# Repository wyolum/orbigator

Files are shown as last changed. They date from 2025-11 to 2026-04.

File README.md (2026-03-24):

# 🌍 Orbigator: The Analog Orbit Propagator






> "What hardware hacker doesn’t have a soft spot for transparent cases? ... [wyojustin] has done a fantastic job of documenting the hardware and software aspects of the build." — **[Hackaday](https://hackaday.com/2026/03/08/the-orbigator-satellite-tracking-with-style/)** ([Full Feature Archive](docs/HACKADAY_FEATURE.md))

**The Orbigator** is an open-source, physical satellite tracker that turns complex orbital mechanics into a desk-side companion. Powered by the **Raspberry Pi Pico 2** and precision **DYNAMIXEL servos**, it physically points to the ISS (or any satellite) in real-time with zero drift.

---

## 🚀 Why the Orbigator?

Inspired by [Will’s Builds ISS tracker](https://hackaday.com/2025/07/08/touch-lamp-tracks-iss-with-style/), the Orbigator introduces several key technical innovations to the DIY tracker space:

### 🔄 Continuous, Uninterrupted Motion
Unlike traditional trackers that use static globes (requiring wire unwinding every orbit), the Orbigator features a **rotating globe**. This allows for smooth, continuous tracking across multiple revolutions without ever needing to reset or "unwind."

### 🎯 LVLH Attitude Control
The orbital mechanics are implemented directly in the hardware geometry (inclination angle). This ensures the satellite pointer maintains a true **LVLH (Local Vertical, Local Horizontal)** attitude throughout the entire pass—exactly how real satellites orient themselves.

### 🧩 Zero-Drift absolute Positioning
Leveraging the 32-bit absolute resolvers in DYNAMIXEL XL330-M288-T motors, the system recovers its orientation instantly after power cycles. No homing, no limits, and no drift—just persistent, mathematical accuracy.

---

## 🛠️ Technical Deep Dive

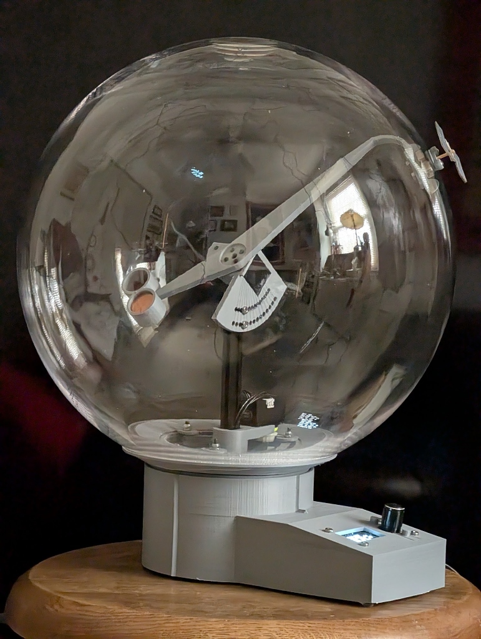
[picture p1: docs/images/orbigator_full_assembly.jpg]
Full Assembly

*Complete Mechanical Assembly: Precision motion and integrated control.*

### Lightweight, High-Performance Propagator
The heart of the Orbigator is a custom, **lightweight SGP4 implementation** running natively on the Pico 2's RISC-V cores. Eschewing heavy ports, it was rolled specifically to provide mathematical accuracy within the visual tolerances of the physical hardware, handling real-time TLE propagation and J2 perturbation effects entirely in MicroPython.

### Split-Screen Radar UI
A custom **SH1106 OLED driver** provides a powerful command center:
*   **Live Radar Plot**: A dynamic "Sky Plot" of the current satellite pass.
*   **Localized World Map**: High-speed bitmask rendering provides a 90° ground track view centered on your observer location.

### Smart Persistence
The system monitors its own state and saves to Flash/SRAM only during ideal intervals (e.g., at equator crossings) to maximize flash lifespan while ensuring a perfect "instant-on" recovery.

---

## 📦 Repository Structure

| Path | Description |
|---|---|
| [**micropython/**](micropython/) | Firmware: SGP4 propagator, UI stacks, and motor drivers. |
| [**fabricate/**](fabricate/) | Mechanical design: OpenSCAD files for 3D printing and assembly. |
| [**kicad/**](kicad/) | Electronics: PCB designs and schematics. |
| [**web/**](micropython/web/) | Dashboard: Real-time control and configuration via web interface. |

---

## ⚡ Quick Start

1.  **3D Print**: High-quality production STLs are located in [**fabricate/stls/Production/**](fabricate/stls/Production/).
2.  **Assemble**: Follow our step-by-step [**Assembly Instructions**](docs/ASSEMBLY.md).
3.  **Flash MicroPython**: Install the Pico 2 firmware.
4.  **Upload Code**: Use Thonny or `mpremote` to copy the `micropython/` files to the board.
5.  **Track!**: Power up and select your satellite from the "SGP4" menu.

---

## 🧾 Bill of Materials (BOM)

### Electronics
*   **Controller**: [Raspberry Pi Pico 2W](https://www.adafruit.com/product/6087)
*   **Motors**: 2x [DYNAMIXEL XL330-M288-T](https://robotis.us/dynamixel-xl330-m288-t/)
*   **Display/UI**: [I2C OLED Display with EC11 Rotary Encoder](https://www.crcibernetica.com/i2c-oled-display-with-ec11-rotary-encoder/) (includes 2x buttons)
*   **RTC**: [DS3232 Precision RTC](https://www.dfrobot.com/product-2304.html)
*   **Logic**: 1x [SN74HC126N Quad Tri-State Buffer](https://www.digikey.com/en/products/detail/texas-instruments/SN74HC126N/376889) (for half-duplex UART)
*   **Passives**: 1x 10kΩ resistor, 2x 4.7kΩ resistors
*   **Power**: 5V 4-5A External Power Supply with [5.5mm DC Barrel Jack](https://www.amazon.com/dp/B0D9B7WR23)

### Hardware & Mechanical
*   **Globe**: [12" Transparent Desktop Globe](https://www.amazon.com/dp/B0086OHL9A)
*   **Bearings**: 3x [13mm OD Carbon Steel Ball Bearings](https://www.amazon.com/dp/B07SV6QSR3) (e.g., 624ZZ) and [High-Performance Skate Bearings](https://www.amazon.com/dp/B09MPMW1XQ)
*   **Fasteners**: Self-tapping screws (included with motors), [M3 Male Stud Mounting Magnets](https://www.kjmagnetics.com/mm-c-12-neodymium-male-stud-mounting-magnet?pl=1.2&pf=), and [Tension Springs](https://www.amazon.com/dp/B076LZ8L1M)
*   **Hardware**: 10-20 US pennies (used as counterweight)
*   **3D Parts**: Printed from the `Production/` folder (PLA or PETG)

---

## 📐 3D Printing (Production Parts)

The following parts are required for the full assembly and can be found in `fabricate/stls/Production/`. **The leading number in the filename indicates the required print quantity.**

*   `1_drive_gear.stl` - Main EQX drive
*   `1_flex_aov_arm.stl` - Satellite pointer arm
*   `1_globe_interface.stl` - Secure mount for the globe
*   `1_inclination_aov_mount.stl` - Hardware-implemented inclination bracket
*   `1_sled_3.stl` - Electronic housing and base
*   `1_full_assembly.stl` - Reference model (not for printing)
*   `3_swingarm.stl` - Differential assembly components
*   `3_shim.stl` - Insert for the skate bearings (see `misc.scad` for 13mm dims)
*   `3_washer.stl` - Vertical stop for the ring gear

---

## 📸 Media: As Seen on [WyoLum Blog](https://wyolum.com/orbigator-real-time-satellite-tracker-with-overhead-alert-radar/)

| [**Earthrise Shot**](docs/images/orbigator_lunar_display.jpg) | [**World Map Tracking**](docs/images/orbigator_worldmap_tracking.png) |
|:---:|:---:|
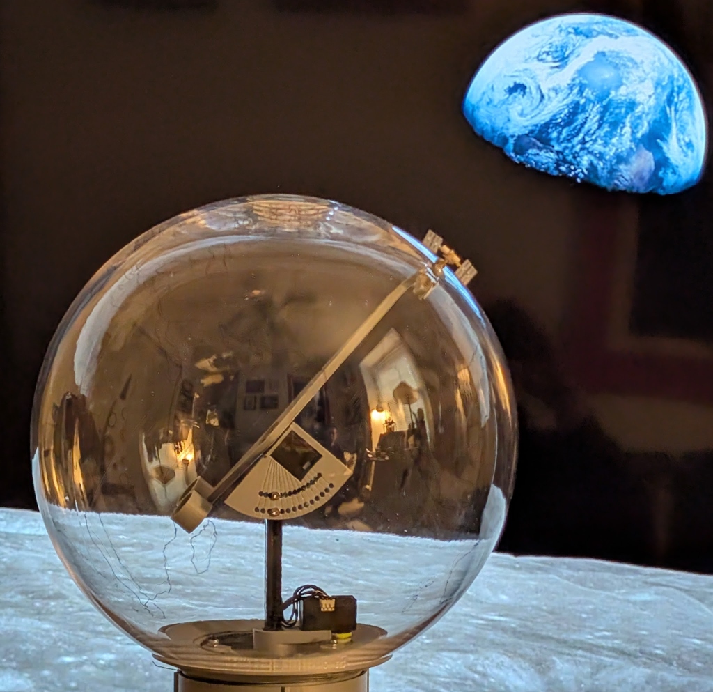
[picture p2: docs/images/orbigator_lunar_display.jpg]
Earthrise
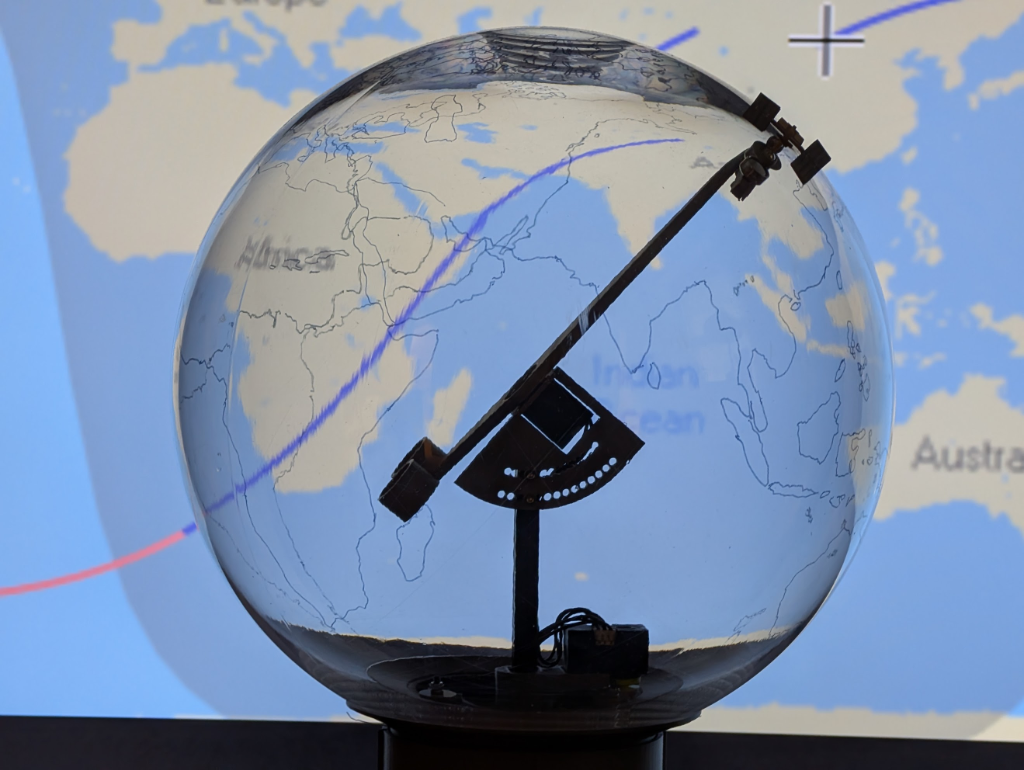
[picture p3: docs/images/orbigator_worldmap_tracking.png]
World Map
|  |  |
| *ISS Tracking with Lunar Projection.* | *Real-time World Map Context.* |

### System Details
| UI & Setup | Electronics | Mechanical Assembly | Technical Render |
|:---:|:---:|:---:|:---:|
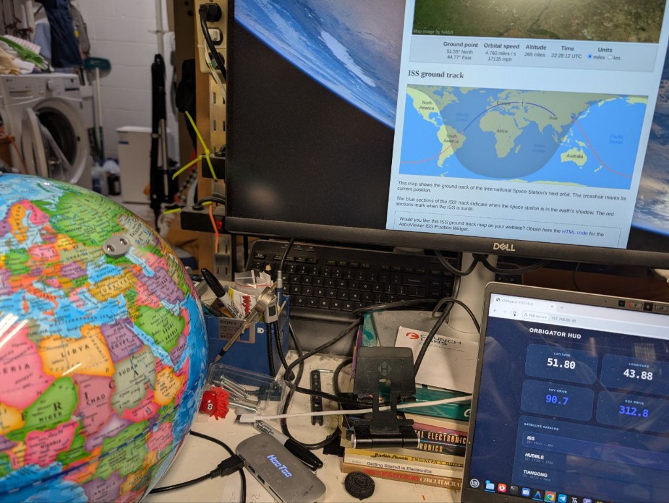
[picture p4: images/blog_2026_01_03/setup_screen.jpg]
Setup
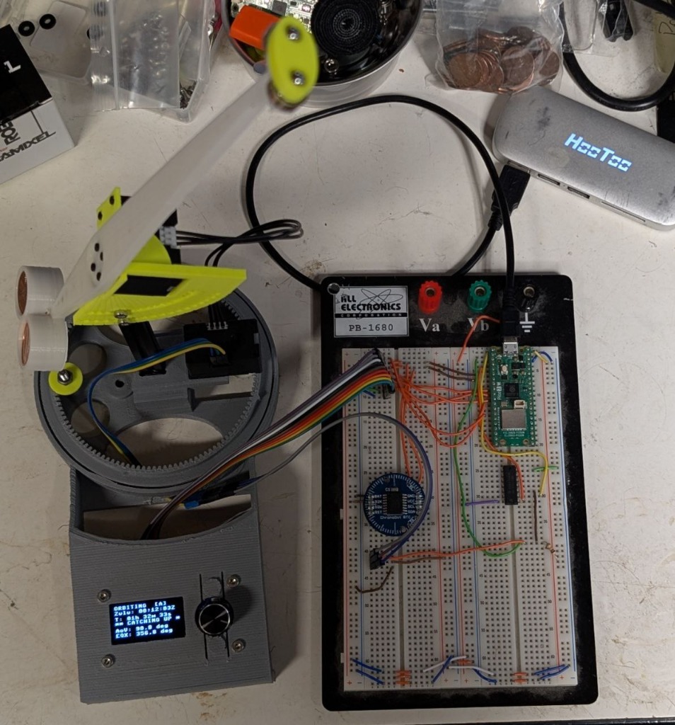
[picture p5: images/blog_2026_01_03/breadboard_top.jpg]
Circuit
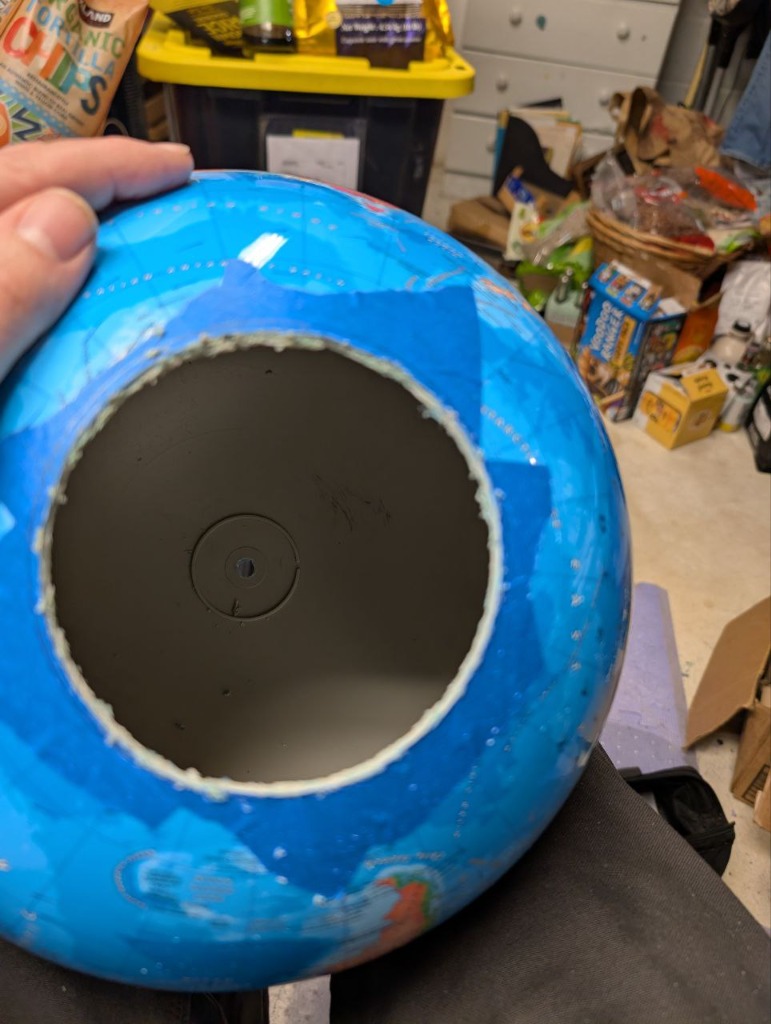
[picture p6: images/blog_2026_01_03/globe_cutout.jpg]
Globe
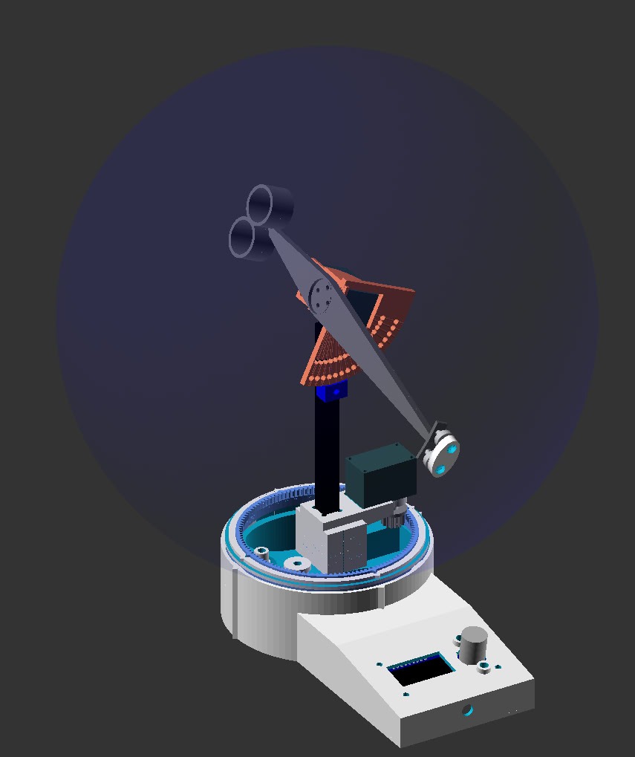
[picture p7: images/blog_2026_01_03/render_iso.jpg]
Technical View
|  |  |  |  |
| *Real-time status* | *Pico 2 & Buffers* | *Internal Hardware* | *Mathematical precision* |

> "A beautiful mix of technical precision and mechanical elegance."

---

## ⚖️ License

Distributed under the MIT License.

---

**Developed with ❤️ by wyojustin**
[GitHub](https://github.com/wyolum/orbigator)

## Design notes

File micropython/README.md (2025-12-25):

# Orbigator MicroPython Firmware

This directory contains the firmware for the Orbigator orbital mechanics simulator project running on a Raspberry Pi Pico 2.

## Main Firmware Architecture

The firmware uses a mode-based architecture for clean UI state management and precise orbital tracking.

### Core Modules
- **`orbigator.py`**: The main entry point. Initializes hardware (motors, display, RTC, encoder) and runs the main event loop.
- **`modes.py`**: Defines the UI states (Orbit, Menu, Setting Editors).
- **`orb_utils.py`**: Core logic for orbital mechanics (Kepler's Laws, J2 Precession), persistence, and motor position reconstruction.
- **`orb_globals.py`**: Central hub for shared state to break circular dependencies.
- **`dynamixel_motor.py`**: Abstraction layer for DYNAMIXEL XL330-M288-T motors.

## Key Features

### 1. Robust State Persistence
The system saves its orbital state (altitude, inclination, absolute motor positions, and timestamp) to `orbigator_config.json`.
- **Flash Protection**: To prevent flash wear, saves only occur when a motor completes a full 360° revolution.
- **Absolute Reconstruction**: On boot, the system reads the raw 0-4095 position from the DYNAMIXEL motors and reconstructs their multi-turn absolute position based on the last saved state.

### 2. Intelligent Catch-up
On startup, the system:
1. Calculates the time elapsed since the last save using the DS3231 RTC.
2. Determines the new target orbital positions.
3. Performs a **shortest-path catch-up move** (max 180°) at a safe speed limit to snap the system into the current real-time state.

### 3. Hardware Safety
- **Speed Caps**: All motors are strictly capped at a **Safety Maximum speed of 10** (Profile Velocity) to prevent mechanical damage or magnets flying off.
- **Soft Limits**: The UI ensures parameters stay within realistic bounds (e.g., altitude 200km - 2000km).

## User Interface (UI)
- **Time Display**: Zulu/UTC format (e.g., `13:24:11Z`).
- **Rotary Encoder**: 
  - **Clockwise**: Navigate Down / Increase Value / Nudge Forward.
  - **Counter-Clockwise**: Navigate Up / Decrease Value / Nudge Backward.
- **Button**: Use the encoder press to toggle targets (AoV vs EQX) or confirm selections.
- **Safety**: The 'Confirm' button is disabled during Orbiting mode to prevent accidental interruptions.

## Hardware Configuration
- **DYNAMIXEL EQX (ID 1)**: Rotates the orbital plane (10.909:1 gear ratio).
- **DYNAMIXEL AoV (ID 2)**: Direct-drive for satellite position.
- **Buffer**: 74HC126 for half-duplex UART communication.
- **RTC**: DS3231 for accurate timekeeping.

## Uploading Firmware
Use `mpremote` or Thonny to upload the entire contents of this directory to your Pico 2.
```bash
mpremote fs cp orb_globals.py orb_utils.py modes.py dynamixel_motor.py orbigator.py :
```

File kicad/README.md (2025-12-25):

# Orbigator KiCad Project

This directory contains the KiCad PCB design files for the Orbigator orbital mechanics simulator.

## Project Structure

```
kicad/
├── orbigator.kicad_pro      # KiCad 8.x project file
├── orbigator.kicad_sch      # Main schematic file
├── orbigator.kicad_pcb      # PCB layout file
├── sym-lib-table            # Symbol library table
├── fp-lib-table             # Footprint library table
├── orbigator.pretty/        # Custom footprints
├── bom/                     # Bill of Materials exports
├── gerber/                  # Gerber files for manufacturing
├── pdf/                     # PDF exports of schematics
├── renders/                 # PCB renders
├── 3D_models/               # Custom 3D models
└── orbigator-backups/       # Automatic backups
```

## Quick Start

1. Open `orbigator.kicad_pro` in KiCad 8.x
2. Review the schematic in the Schematic Editor
3. Use the reference documentation in the parent directory:
   - `ORBIGATOR_CIRCUIT_DIAGRAM.txt` - ASCII circuit diagram
   - `ORBIGATOR_PIN_ASSIGNMENTS.txt` - Pin assignments
   - `NOTE_FOR_ANOOL_I2C_PULLUPS.txt` - Critical design notes
   - `BOM.md` - Detailed component specifications

## Key Design Requirements

### Critical Components
- **I2C Pull-ups**: 4.7kΩ resistors on SDA and SCL (REQUIRED for multi-device bus)
- **RTC Backup**: 0.47F supercapacitor with 47Ω charging resistor (recommended)
- **DATA Bus Pull-up**: 10kΩ resistor to +5V for DYNAMIXEL communication

> **Note for Anool**: For the RTC (DS3231), you can choose between:
> 1. Using a ChronoDot module breakout (simple pinout connection)
> 2. Integrating the DS3231 chip directly with battery backup (CR2032)
> 3. Integrating the DS3231 chip directly with supercapacitor backup (0.47F)
> 
> The choice is yours based on board space, cost, and maintenance preferences.

### Power Requirements
- **3.3V Rail**: Pico 2, 74HC126, OLED, RTC (low current)
- **5V Rail**: DYNAMIXEL motors (4-5A external supply required)

### Connectors
- **DYNAMIXEL**: 3-pin JST connectors (daisy-chained)
- **Encoder**: 5-pin header (A, B, SW, VCC, GND)
- **Power**: Barrel jack or terminal block for 5V input

## Design Notes

This PCB is designed to be a single-board controller for the Orbigator display.
All components should be easily hand-solderable (through-hole or large SMD).

The design prioritizes:
- Reliability (proper pull-ups, decoupling)
- Serviceability (labeled connectors, test points)
- Compactness (suitable for display base mounting)

## Manufacturing

Standard 2-layer PCB:
- Thickness: 1.6mm
- Copper: 1oz
- Finish: HASL or ENIG
- Minimum trace: 0.2mm
- Minimum clearance: 0.2mm

## Author

Design by Anool Mahidharia (WyoLum)
Based on specifications by Justin Shaw

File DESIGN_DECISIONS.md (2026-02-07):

# Orbigator Design Decisions

This document captures the authoritative design decisions for the Orbigator motor control system. 
**This is the source of truth. Do not deviate from these specifications.**

---

## EQX Motor Recovery at Boot

### Goal
Recover the motor's absolute position from saved state, then slew to the correct orbital target.

### Algorithm (Bounded-Delta Recovery)

```python
CPR = 4096  # Counts per revolution

saved_mod = saved_ext % CPR
hw_mod = raw_ticks % CPR
d_mod = (hw_mod - saved_mod) % CPR  # Always 0..4095

# ALWAYS use shortest path
delta = d_mod if d_mod <= (CPR // 2) else d_mod - CPR

ext_now = saved_ext + delta
```

### Why Shortest Path?
- State is saved at least once per motor revolution
- Therefore `|delta| < half revolution` is always correct
- `d_mod = 4095` means `-1`, not `+4095`

### Boot Sequence
1. **Recover** - Read encoder, apply bounded-delta to get absolute position
2. **Compute** - Calculate orbital target from propagator (where satellite IS)
3. **Slew** - Command motors to target position (catch-up is expected and correct)

---

## Calibration Offset (`offset_degrees`)

### What It Is
A persistent calibration value that maps encoder ticks to real-world degrees.

Example: The physical ring's "0° EQX" mark is at encoder position 527. 
Therefore `offset_degrees = 527 * (360/4096) / gear_ratio`.

### Where It Lives
- Stored in `orbigator_config.json` under `motors.eqx.offset_deg`
- Applied in `DynamixelMotor.get_angle_degrees()`:
  ```python
  output_degrees = (abs_ticks * deg_per_tick / gear_ratio) - offset_degrees
  ```

### How To Calibrate
Use EQXCalibrationMode: set the displayed angle to match the physical position, then save.

---

## Motor Control Philosophy

### Hardware is Truth
- The encoder reading is the ground truth for position
- Software state (SRAM) is used only to recover multi-turn count

### Orbital Model is Target
- The propagator calculates where the satellite IS in real-time
- Motors slew to match the orbital target
- "Catch-up" slewing on boot is expected when position != target

### Direction Constraints
- **AoV Motor**: Forward-only during tracking (cable safety), bidirectional for nudging
- **EQX Motor**: Shortest path always

---

## State Persistence

### When State is Saved
- On revolution crossing (turn change callback)
- On mode exit (transition to Menu)
- On clean shutdown (Ctrl+C handler)
- On settings changes

### What is Saved
- Motor absolute tick counts (`aov_abs_ticks`, `eqx_abs_ticks`)
- Current positions (`aov_deg`, `eqx_deg`)
- Mode ID and satellite name
- Revolution count

### Storage Priority
1. RTC SRAM (instant, no flash wear)
2. Flash fallback (`state.json`)

---

## Terminology

| Term | Meaning |
|---|---|
| `offset_degrees` | Calibration offset - maps encoder to real-world angle |
| `delta` | Bounded signed difference between saved and current position |
| `abs_ticks` | Extended position count (multi-turn capable) |
| `output_degrees` | Final angle after gear ratio and calibration offset |
| `hw_mod` | Current encoder reading modulo 4096 |
| `saved_mod` | Saved position modulo 4096 |

---

## Anti-Patterns (What NOT To Do)

❌ **Do NOT** add runtime phase offsets to "shift the sky"  
❌ **Do NOT** command motors from `mode.enter()` during boot sequence  
❌ **Do NOT** use direction constraints for boot recovery (always shortest path)  
❌ **Do NOT** interpret `d_mod = 4095` as `+4095` (it means `-1`)  

---

*Last Updated: 2026-02-07*

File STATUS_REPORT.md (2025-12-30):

# Orbigator Project Status Report - Dec 29, 2025

## 🛰️ Current Mission Status: OPTIMIZED & TUNED
All core software and motor tuning objectives have been met. The system is verified stable and running on the hardware.

---

## 1. Motor PID Tuning (Crucial)
- **Hardware**: DYNAMIXEL **XC330-M288-T** (High-torque metal gear version).
- **Issue**: Mechanical resonance/wobble on the long AoV (Altitude of Venus/Satellite) arm.
- **Solution**: "Softer" tune to decouple motor pulses from arm resonance.
- **Final Verified Gains**: **P=600**, **I=0**, **D=0**.
- **Persistence**: Fixed in `orbigator.py` boot sequence.
- **Result**: Zero shaking during full 360° sweeps at operational speeds (Speed=2).

- **Web API (Observability)**: Added real-time motor monitoring. `/api/status` and `/api/motors` now report live PID gains and speed limits.

## 3. Motor Longevity & Reliability
- **Analysis**: At 1 rev per 90 mins (~0.11 rpm), the XC330 motor is operating so gently that its expected lifetime is measured in decades (very likely longer than the rest of the system).
- **Technical Note**: ~5,840 revolutions/year. Even under conservative metal-gear wear assumptions (≥100,000 revs), service life exceeds 17 years; realistic estimates are far higher. 
- **Control Factor**: Our P-only tuning (P=600) and velocity-based control ensure smooth motion free of hunting or micro-oscillation, maximizing gear train life.

## 4. UI & Experience Enhancements
- **Accelerated Encoder**: Velocity-based nudging (0.1° fine, 1.0° max). Allows fast 180° traversal (one turn) while maintaining high precision.
- **Graphical Degree Symbol**: Custom 3x3 pixel ring replaces "deg" text for a professional, premium aesthetic.
- **Enhanced Catch-up Display**: OLED now shows actual motor readouts (`ACT: A123° E456°`, modulo 360) during seek/initialization for physical state transparency.

## 5. Toolset Improvements
- **Incremental Sync**: New `sync.sh` + `sync_to_pico.py` suite. Uses a `sync_whitelist.txt` to push only modified project files (ignoring `.pico_state.json`, `stls/`, etc.).
- **Live Tuner**: `tune_motors.py` allow host-side PID/Speed adjustment with immediate MicroPython code injection and motion testing.

## 6. Mechanical & CAD
- **Globe Diameter**: Adjusted to **295mm** (11.82") for the new assembly.
- **CAD Cleanup**: Removed AI-generated "subterranean display" base. Updated `dynamixel_aov_arm.scad` and `full_assembly.scad` for new globe radius.
- **Mechanical Iteration**: `globe_interface_ring` v1 (1.01) was too tight. v2 (1.02) currently printing on Ultimaker 3 (Smooth progress, ~1.5h remaining).

## 7. Repository Status
- **GitHub**: All drivers, tools, and SCAD modifications pushed to `wyolum/orbigator`.
- **Branch**: `main` is current.

---
**Next Action**: Verify mechanical fit and re-check PID gains if the new arm changes inertia significantly.

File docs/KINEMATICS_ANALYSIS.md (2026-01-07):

# Kinematic Analysis: Ascending vs Descending

## Current Mapping (SGP4/Orbit Mode)
In `propagators.py`, the motors are driven as follows:
- **AoV (Angle of Vertical)** = Argument of Latitude ($u = \nu + \omega$)
- **EQX (Equinox)** = Longitude of Ascending Node ($\Omega - \text{GMST}$)

### AoV Ranges
- **$0^\circ - 180^\circ$**: Ascending Pass (Northbound crossing $\to$ North Apex $\to$ Southbound crossing). This creates the "Front" or "Ascending" arc.
- **$180^\circ - 360^\circ$**: Descending Pass (Southbound crossing $\to$ South Apex $\to$ Northbound crossing).

## Two Solutions for Static Targets
You are correct. If we implemented a mode to "Point to Latitude $L$", there are two valid mechanical configurations (assuming $|L| < i$):

1.  **Ascending Solution**:
    *   Set AoV to $u_1$ where $\sin(u_1) = \sin(L) / \sin(i)$ and $\cos(u_1) > 0$.
    *   Adjust EQX ring so the ascending node is to the West of the target.
    *   *Result*: The arm is in the "Front" ($0-90^\circ$) or just past it.
2.  **Descending Solution**:
    *   Set AoV to $u_2 = 180^\circ - u_1$.
    *   Adjust EQX ring so the descending node is to the West of the target.
    *   *Result*: The arm is in the "Back" ($90-180^\circ$ range of the sine wave, i.e. going down).

### Implication
For satellite tracking, the physics handles this automatically (the satellite is only at one spot at a time).
If we added a **"Point to City"** mode, we would need to choose one. "Ascending in Front" effectively means we'd prefer the solution where AoV $\in [0, 180]$ if possible (though for Southern hemisphere targets, we might need the "Descending" or "South" range).

## Mismatched Inclination Strategy
 **Hypothesis**: "As long as physical inclination ($i_{phys}$) is large enough, we can hit any lat/lon."

This is correct.
*   **Condition**: $i_{phys} \ge |Lat_{target}|$
*   **Implication**: We can track *any* satellite whose inclination $i_{sat} \le i_{phys}$.

### The Transformation (Virtual Inclination)
When $i_{phys} \ne i_{sat}$, the simple mapping ($AoV = u$, $EQX = \Omega$) breaks. We must compute explicit target angles:

Given target Satellite Lat $\phi_{sat}$ and Lon $\lambda_{sat}$ (relative to Earth-Fixed frame):

1.  **Solve for Arm Angle (AoV) $\theta$**:
    The height (sin Lat) is determined solely by the arm angle and physical inclination.
    $$\sin(\phi_{sat}) = \sin(i_{phys}) \cdot \sin(\theta)$$
    $$\theta = \arcsin\left(\frac{\sin(\phi_{sat})}{\sin(i_{phys})}\right)$$
    *Note: This gives two solutions for $\theta$ (Ascending vs Descending).*

2.  **Solve for Base Angle (EQX) $\psi$**:
    The arm's rotation contributes to the longitude. We need to find the longitude offset $\Delta\lambda_{arm}$ caused by the arm.
    $$\tan(\Delta\lambda_{arm}) = \cos(i_{phys}) \cdot \tan(\theta)$$
    The EQX motor must then rotate to place the node such that:
    $$EQX_{target} = \lambda_{sat} - \Delta\lambda_{arm}$$

This allows the Orbigator to act as a **Universal Tracker** for any orbit lower than its physical inclination.

## Definitions
**"Stored Inclination"**: The value currently stored in `orbigator_state.json` (variable `g.orbital_inclination_deg`).
*   **Role**: This acts as the **Physical Inclination** ($i_{phys}$) of the mechanism.
*   **Usage**: In Universal Tracker mode, this value is fixed by the hardware construction and used for the coordinate transformation, while the target's inclination comes from the TLE or target coordinates.

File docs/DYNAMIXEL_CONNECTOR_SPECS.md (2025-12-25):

# DYNAMIXEL XL-330 Motor Connector Specifications

The DYNAMIXEL XL-330 uses a **3-pin JST-GH family connector** on the servo PCB.

## Key Characteristics
- **Pins**: 3 pins in a single row
- **Pitch**: 1.25 mm (Note: User mentioned 2.54mm but JST-GH is 1.25mm; Robotis XL330 uses 1.25mm JST-GH)
- **Locking**: Friction lock latch on the housing
- **Polarization**: Keyed housing to prevent reverse mating
- **Often called**: JST GH series (Note: XH is incorrect — GH is the one Robotis uses)

Official DYNAMIXEL Pinout

📌 **Why This Matters**: Generic servo wires (like typical RC servo cables) will not lock in reliably. They can wiggle out over time inside mechanical motion systems like the Orbigator globe.

---

## 🔌 Recommended Connector Components

### 1. JST-GH Crimp Housings (3-pin)
Use these on the servo cable that mates to the XL-330.
- **Part**: JST GHR-03V-S (3-pin housing)
- **Verified Link**: [DigiKey - GHR-03V-S](https://www.digikey.com/en/products/detail/jst-sales-america-inc/GHR-03V-S/2978418)
- **Features**: Designed for movement without loosening.

### 2. JST-GH Crimp Pins (for cable ends)
You must use crimp pins made specifically for the GH series (26-30 AWG).
- **Part**: JST SSHL-002T-P0.2
- **Verified Link**: [DigiKey - SSHL-002T-P0.2](https://www.digikey.com/en/products/detail/jst-sales-america-inc/SSHL-002T-P0.2-608779/608779)
- **Important**: Crimp them onto your wires with a proper tool — do not solder directly to the housing.

### 3. JST-GH PCB Mounting Headers
If you are designing your own PCB or breakout board, use these SMT headers to mate with the servo cables.
- **Top Entry (Vertical)**: [JST BM03B-GHS-TBT (DigiKey)](https://www.digikey.com/en/products/detail/jst-sales-america-inc/BM03B-GHS-TBT/608693)
- **Note**: A side-entry (horizontal) version also exists for low-profile applications.
- **Note**: These are SMT (Surface Mount) components. Through-hole versions are not standard for the GH series.

### 4. Matching Servo Cable Assemblies
Pre-assembled 3-wire GH connector cables (often sold as Robotis servo harnesses).
- **Pro Tip**: The **standard 180mm (7.09") cables** that ship with the XL-330 are actually the perfect length for the internal Orbigator assembly — they provide just enough slack for movement without cluttering the globe interior.
- **Extension**: [Robotis 500mm Extension Cable](https://www.robotis.us/robot-cable-wp-500mm-extension-cable/)
- **Robotis P/N**: Robot Cable-WP 3P 500mm

---

## 🛠 Tips to Keep Them Secure Inside the Globe

### A) Use strain relief
Even with locking connectors, tension from motion can pull wires. Always add:
- Hot-glue at strategic anchor points
- Adhesive cable clips
- Zip-ties to internal standoffs
This prevents mechanical load on the small JST latch.

### B) Don’t rely on bare headers
Avoid using bare pins without a housing inside the globe. Vibration will eventually shake them loose.
- **Always use**: Crimped GH housing on the wire side mated to the servo board.

### C) Board Design
If you’re designing your own daughterboard or breakout:
- Use headers that friction-lock with JST-GH.
- Add a small retention clip or silkscreen guidance to ensure the connector is captive.

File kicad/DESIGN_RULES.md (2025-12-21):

# Design Rules Configuration for Orbigator PCB

This file documents the design rules used for the Orbigator PCB.
These are already configured in `orbigator.kicad_pro` but documented here for reference.

## Trace Widths

| Net Class | Minimum Width | Recommended Width | Notes |
|---|---|---|---|
| Default | 0.25mm | 0.25mm | Signal traces |
| Power (+5V, GND) | 1.0mm | 1.5mm | Motor current (up to 2A) |
| +3.3V | 0.5mm | 0.5mm | Low current rail |

## Clearances

| Type | Minimum | Recommended | Notes |
|---|---|---|---|
| Trace to trace | 0.2mm | 0.3mm | Standard clearance |
| Trace to pad | 0.2mm | 0.25mm | |
| Pad to pad | 0.2mm | 0.25mm | |
| Copper to edge | 0.5mm | 1.0mm | Keep copper away from board edge |

## Vias

| Parameter | Value | Notes |
|---|---|---|
| Diameter | 0.8mm | Standard via |
| Drill | 0.4mm | Standard drill |
| Annular ring | 0.2mm minimum | (Diameter - Drill) / 2 |

**Via Usage:**
- Use multiple vias for ground connections
- Use thermal relief for ground pads on ground pour
- Avoid vias in pads unless necessary

## Holes

| Type | Diameter | Notes |
|---|---|---|
| Mounting holes | 3.2mm | M3 screws, non-plated |
| Through-hole pads | Varies | Per component datasheet |

## Copper Pours

| Layer | Net | Priority | Notes |
|---|-----|---|---|
| Bottom (B.Cu) | GND | High | Fill entire layer |
| Top (F.Cu) | None | - | Route signals only |

**Ground Pour Settings:**
- Clearance: 0.5mm
- Minimum width: 0.5mm
- Thermal relief: 4 spokes, 0.5mm width
- Remove isolated islands: Yes

## Text & Silkscreen

| Element | Size | Thickness | Notes |
|---|---|---|---|
| Reference designators | 1.0mm | 0.15mm | Must be readable |
| Values | 1.0mm | 0.15mm | Optional on silkscreen |
| Board text | 1.5mm | 0.3mm | Title, version |
| Company name | 1.2mm | 0.25mm | WyoLum |

**Silkscreen Rules:**
- Minimum line width: 0.12mm
- Minimum text height: 0.8mm
- Keep 0.2mm clearance from pads
- No silkscreen on pads or vias

## Solder Mask

| Parameter | Value | Notes |
|---|---|---|
| Clearance | 0.0mm | Use manufacturer default |
| Minimum width | 0.0mm | Use manufacturer default |

## Manufacturing Constraints

Based on standard PCB manufacturers (JLCPCB, PCBWay, etc.):

| Parameter | Minimum | Recommended | Notes |
|---|---|---|---|
| Trace width | 0.15mm | 0.25mm | We use 0.25mm |
| Trace spacing | 0.15mm | 0.2mm | We use 0.2mm |
| Via drill | 0.3mm | 0.4mm | We use 0.4mm |
| Via diameter | 0.5mm | 0.8mm | We use 0.8mm |
| Hole to hole | 0.25mm | 0.5mm | |
| Board outline | 0.1mm | 0.1mm | Edge.Cuts layer |

## Net Classes

### Default
- Track width: 0.25mm
- Via diameter: 0.8mm
- Via drill: 0.4mm
- Clearance: 0.2mm
- Applies to: All signal nets

### Power
- Track width: 1.0mm
- Via diameter: 0.8mm
- Via drill: 0.4mm
- Clearance: 0.2mm
- Applies to: +5V, +3V3, GND

## Special Considerations

### I2C Bus (SDA, SCL)
- Keep traces short (< 50mm preferred)
- Route together with matched lengths
- Avoid routing near noisy signals
- Pull-ups must be close to master (Pico)

### DYNAMIXEL DATA Bus
- Single trace, keep short
- 10kΩ pull-up to +5V required
- Avoid stubs or branches

### Power Distribution
- Star topology from power input
- Wide traces for motor power
- Multiple vias for ground connections
- Decoupling caps close to ICs

### High-Speed Signals
- None in this design (all signals < 1MHz)
- Standard routing practices sufficient

## Layer Stack

```
┌─────────────────────┐
│   F.SilkS (White)   │  Silkscreen
├─────────────────────┤
│   F.Mask (Green)    │  Solder mask
├─────────────────────┤
│   F.Cu (Copper)     │  Top copper layer (signals)
├═════════════════════┤
│   Core (FR4)        │  1.6mm substrate
├═════════════════════┤
│   B.Cu (Copper)     │  Bottom copper layer (ground pour)
├─────────────────────┤
│   B.Mask (Green)    │  Solder mask
├─────────────────────┤
│   B.SilkS (White)   │  Silkscreen
└─────────────────────┘
```

## DRC Settings

All design rule checks are configured in `orbigator.kicad_pro` under:
- `board.design_settings.rules`
- `board.design_settings.rule_severities`

**Critical Checks:**
- Unconnected items: Error
- Clearance violations: Error
- Track width violations: Error
- Hole clearance: Error
- Copper edge clearance: Error

## References

- KiCad Documentation: https://docs.kicad.org/
- IPC-2221: Generic Standard on Printed Board Design
- IPC-2222: Sectional Design Standard for Rigid Organic Printed Boards

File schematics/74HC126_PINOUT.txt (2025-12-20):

SN74HC126N PINOUT DIAGRAM
=========================
Quad Tri-State Buffer (14-pin DIP)

         +-----v-----+
    1OE  |1        14| VCC (3.3V)
    1A   |2        13| 4OE
    1Y   |3        12| 4A
    2OE  |4        11| 4Y
    2A   |5        10| 3OE
    2Y   |6         9| 3A
    GND  |7         8| 3Y
         +-----------+

ORBIGATOR CONNECTIONS (Using Buffer 1 only):
=============================================

Pin 1  (1OE) ← GP2 (Direction Control)
Pin 2  (1A)  ← GP0 (UART TX from Pico)
Pin 3  (1Y)  → DATA BUS (to Dynamixel motors)
Pin 7  (GND) → Common Ground
Pin 14 (VCC) → 3.3V from Pico

UNUSED PINS (Buffers 2, 3, 4):
- Pins 4, 5, 6 (Buffer 2)
- Pins 8, 9, 10 (Buffer 3)
- Pins 11, 12, 13 (Buffer 4)
- Leave floating or tie OE pins to GND to disable

OPERATION:
==========
When 1OE (Pin 1) = HIGH:
  - Buffer is ENABLED
  - 1Y (Pin 3) outputs the signal from 1A (Pin 2)
  - Pico transmits to motors

When 1OE (Pin 1) = LOW:
  - Buffer is TRI-STATED (high impedance)
  - 1Y (Pin 3) is disconnected
  - Motors can transmit back to Pico on DATA line

SIGNAL FLOW:
============
TX Mode (GP2=HIGH):
  Pico GP0 → Pin 2 (1A) → Pin 3 (1Y) → DATA BUS → Motors

RX Mode (GP2=LOW):
  Motors → DATA BUS → Pico GP1 (direct connection)
  (Pin 3 is tri-stated, doesn't interfere)

CRITICAL NOTES:
===============
1. VCC must be 3.3V (74HC series is 3.3V compatible)
2. Do NOT use 74LS126 (requires 5V, not compatible)
3. GP2 must be set HIGH before transmitting
4. GP2 must be set LOW to receive motor responses
5. Add 0.1µF bypass capacitor between VCC and GND

DATASHEET:
==========
Texas Instruments SN74HC126N
https://www.ti.com/lit/ds/symlink/sn74hc126.pdf

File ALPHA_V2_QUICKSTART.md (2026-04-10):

# Orbigator PCB V2: Alpha Tester Quick Start Guide

This guide covers bringing up a bare PCB V2 board and testing peripherals.

## 1. Hardware Connections
1. Connect the Pico 2 to the host via USB for data.
2. Connect a 5V power supply to the DC Barrel Jack (J1). The V2 power path isolates the motors from the USB 5V rail; UART Dynamixels will not respond over USB power alone.

## 2. Firmware Deployment
1. Format the Pico 2 flash using `mpremote`:
   ```bash
   mpremote exec "import os; [os.remove(f[0]) for f in os.ilistdir() if f[1] != 0x4000]"
   mpremote exec "import os; [os.rmdir(f[0]) for f in os.ilistdir() if f[1] == 0x4000]"
   ```

2. Clear the local sync checkpoint:
   ```bash
   rm .last_sync
   ```

3. Run the sync script:
   ```bash
   ./sync.sh
   ```

## 3. Hardware Diagnostics
Run the peripheral diagnostic script:

```bash
mpremote run micropython/utils/super_test.py
```

**Diagnostic Output Variables:**
1. **Row 1:** RTC Date (`YY-MM-DD`) and SRAM status (`SRAM:OK`). 
2. **Row 2:** Current phase of the active motor (`Mot: EQX 123dg`).
3. **Row 3:** RTC Time (`Time:12:30:15`).
4. **Row 4:** Encoder Value (`Enc:X`) and switch states `[X][B][C]` (Encoder Click, Back, Confirm).

**Validation Steps:**
1. Turn the rotary encoder. The active motor should advance 10 degrees per tick.
2. Press the `CONFIRM` button. The OLED will toggle to `Mot: AoV`. Turn the encoder to verify physical AoV response.

## 4. Run Main Application
Terminate `super_test.py` (Ctrl+C). Execute `orbigator.py`:

```bash
mpremote run micropython/orbigator.py
```

### Runtime Notes:
1. **Directional Deadband:** Boot alignment respects a forward-only (`direction=1`), 20-degree deadband. If the calculated target is slightly behind the current physical state, the motor will idle until the simulated target catches up.
2. **World Map:** The `sync.sh` payload includes the pre-compiled `world_mask.bin` asset. The map will render immediately upon entering Orbit Mode without invoking runtime generation routines.

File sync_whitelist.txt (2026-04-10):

# Orbigator Sync Whitelist - Required files for full application
# Hardware Drivers
pins.py
oled_display.py
rotary_encoder.py
ssd1306.py
sh1106.py
ds323x.py
rtc.py
buttons.py
dynamixel_extended_utils.py
dynamixel_motor.py
absolute_motor.py
persistence.py
world_map.py
radar_display.py

# Architecture & Capabilities
capabilities.py
networking.py
ntp_sync.py

# Core Application
orbigator.py
modes.py
orb_utils.py
orb_globals.py
input_utils.py
propagate.py
web_server.py
satellite_position.py
satellite_catalog.py
tle_fetch.py
track_ll_chunk.py
sgp4.py
wifi_setup.py
web/index.html

# Demos
demos/demo_eqx_negative.py
demos/demo_eqx_recovery.py

# Data & Config
orbigator_config.json
world.dat
world_mask.bin

# Directories
[DIRS]
web

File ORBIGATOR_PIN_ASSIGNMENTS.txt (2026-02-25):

ORBIGATOR COMPLETE PIN ASSIGNMENTS
Raspberry Pi Pico 2 with DYNAMIXEL XL330-M288-T Motors
========================================================

COMPONENT OVERVIEW
==================
- Raspberry Pi Pico 2 (main controller)
- 2x DYNAMIXEL XL330-M288-T servos (EQX and AoV motors)
- SN74HC126N quad tri-state buffer (half-duplex UART)
- SH1106/SSD1306 OLED display (128x64)
- DS3232 RTC (ChronoDot)
- Rotary encoder with push button
- Back button (on combo board)
- Confirm button (on combo board)
- 10kΩ pull-up resistor (DYNAMIXEL DATA line)

========================================================
RASPBERRY PI PICO 2 PIN ASSIGNMENTS
========================================================

DYNAMIXEL COMMUNICATION (UART0 + 74HC126 Buffer)
-------------------------------------------------
GP0  (Pin 1)  → UART0 TX → 74HC126 Pin 2 (1A - Input)
GP1  (Pin 2)  → UART0 RX → DYNAMIXEL DATA line (shared)
GP2  (Pin 4)  → Direction Control → 74HC126 Pin 1 (1OE - Output Enable)

I2C0 (OLED Display + RTC)
--------------------------
GP4  (Pin 6)  → I2C0 SDA → OLED SDA + DS3232 SDA
GP5  (Pin 7)  → I2C0 SCL → OLED SCL + DS3232 SCL

ROTARY ENCODER
--------------
GP6  (Pin 9)  → Encoder A (with internal pull-up)
GP7  (Pin 10) → Encoder B (with internal pull-up)
GP8  (Pin 11) → Encoder Switch (with internal pull-up)

USER INTERFACE BUTTONS
----------------------
GP9  (Pin 12) → Back Button (with internal pull-up)
GP10 (Pin 14) → Confirm Button (with internal pull-up)

POWER
-----
3V3(OUT) (Pin 36) → 74HC126 VCC (Pin 14)
GND      (Pin 3, 8, 13, 18, 23, 28, 33, 38) → Common ground

UNUSED PINS (Available for Future Expansion)
---------------------------------------------
GP3, GP11-GP22, GP26-GP28

========================================================
SN74HC126N TRI-STATE BUFFER CONNECTIONS
========================================================
Pin 1  (1OE)  ← GP2 (Direction Control)
Pin 2  (1A)   ← GP0 (UART TX)
Pin 3  (1Y)   → DYNAMIXEL DATA BUS
Pin 4  (2OE)  - Not used
Pin 5  (2A)   - Not used
Pin 6  (2Y)   - Not used
Pin 7  (GND)  ← Common ground
Pin 8  (3Y)   - Not used
Pin 9  (3A)   - Not used
Pin 10 (3OE)  - Not used
Pin 11 (4Y)   - Not used
Pin 12 (4A)   - Not used
Pin 13 (4OE)  - Not used
Pin 14 (VCC)  ← Pico 3.3V

========================================================
DYNAMIXEL DATA BUS (Shared Half-Duplex)
========================================================
74HC126 Pin 3 (1Y) ──┬── DYNAMIXEL DATA
GP1 (UART RX)        ┤
10kΩ pull-up to 5V  ─┘

DYNAMIXEL MOTOR 1 (EQX - ID 1)
------------------------------
Pin 1 (GND)   → Common ground
Pin 2 (VDD)   → 5V power supply
Pin 3 (DATA)  → DATA BUS

DYNAMIXEL MOTOR 2 (AoV - ID 2)
------------------------------
Pin 1 (GND)   → Common ground
Pin 2 (VDD)   → 5V power supply
Pin 3 (DATA)  → DATA BUS

========================================================
OLED DISPLAY (SH1106 or SSD1306)
========================================================
VCC → Pico 3.3V
GND → Common ground
SDA → GP4 (I2C0 SDA)
SCL → GP5 (I2C0 SCL)

I2C Address: 0x3C (default)
Frequency: 100 kHz

========================================================
DS3232 RTC (ChronoDot)
========================================================
VCC → Pico 3.3V (or 5V if available)
GND → Common ground
SDA → GP4 (I2C0 SDA, shared with OLED)
SCL → GP5 (I2C0 SCL, shared with OLED)

I2C Address: 0x68 (default)
Frequency: 100 kHz

========================================================
ROTARY ENCODER
========================================================
A   → GP6 (with internal pull-up enabled)
B   → GP7 (with internal pull-up enabled)
SW  → GP8 (with internal pull-up enabled)
GND → Common ground
VCC → Not connected (using internal pull-ups)

========================================================
POWER DISTRIBUTION
========================================================

3.3V RAIL (from Pico)
---------------------
- 74HC126 VCC (Pin 14)
- OLED VCC
- DS3232 VCC (can also use 5V)

5V RAIL (External Power Supply)
--------------------------------
- DYNAMIXEL Motor 1 VDD
- DYNAMIXEL Motor 2 VDD
- 10kΩ pull-up resistor (top side)

GROUND (Common)
---------------
- Pico GND (multiple pins)
- 74HC126 GND (Pin 7)
- DYNAMIXEL Motor 1 GND
- DYNAMIXEL Motor 2 GND
- OLED GND
- DS3232 GND
- Rotary encoder GND
- External 5V supply GND

========================================================
CRITICAL NOTES
========================================================

1. DYNAMIXEL PINOUT (JST 3-Pin)
   - Pin 1 (GND) is always on the OUTER edge when looking at connector
   - Connectors on both sides of motor are MIRRORED
   - Use multimeter continuity test to verify GND (beeps to motor case)

2. HALF-DUPLEX UART
   - GP2 HIGH = Pico transmits (buffer enabled)
   - GP2 LOW  = Motor transmits (buffer tri-stated)
   - GP1 always listens on DATA line

3. I2C BUS
   - Shared between OLED and RTC
   - Both devices have different addresses (no conflict)
   - 100 kHz frequency for reliability

4. POWER REQUIREMENTS
   - Pico: USB 5V or VSYS
   - Motors: External 5V 4-5A supply (NOT from Pico!)
   - Common ground between Pico and motor supply is CRITICAL

5. GEAR RATIOS
   - EQX Motor: 11T drive gear → 120T ring gear (10.909:1)
   - AoV Motor: Direct drive (1:1)

========================================================
FIRMWARE CONFIGURATION
========================================================

File: orbigator.py

UART Configuration:
- Baud rate: 57600
- Data bits: 8
- Parity: None
- Stop bits: 1

Motor IDs:
- AoV Motor: ID 2
- EQX Motor: ID 1

Operating Mode:
- Extended Position Control Mode (Mode 4)

Encoder:
- DETENT_DIV: 4 (counts per detent)
- Direction: Reversed in ISR

I2C:
- Frequency: 100 kHz
- Auto-detect OLED type (SH1106/SSD1306)

========================================================
END OF PIN ASSIGNMENTS
========================================================

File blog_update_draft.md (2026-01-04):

# Orbigator Dev Log: From Simulation to Reality

It’s been a while since the last update, and the Orbigator has evolved from a collection of parts and Python scripts into a fully integrated, silent, and precise satellite tracking machine.

Here is the story of how we got here.

Setup with HUD

## 1. The Hardware Pivot: Steppers vs. Smart Servos
We started where most builds start: **Stepper Motors**. They are cheap and ubiquitous. But for a device meant to sit on a desk and track the ISS silently 24/7, they had drawbacks. They vibrate, they make noise ("singing"), and crucially, they are **open-loop**—if the arm gets bumped, the system loses its place and stays lost.

We pivoted to **Dynamixel XL330** smart servos.
*   **Silence**: They are virtually silent at tracking speeds.
*   **Closed-Loop**: They know their absolute position. If you push the arm, it fights back (torque!).
*   **Cabling**: They daisy-chain on a single bus, drastically reducing the rat's nest of wires.

## 2. The Brain Transplant: MicroPython on Pico 2W
We moved the logic from a desktop PC to the **Raspberry Pi Pico 2W**. This brought its own set of challenges, primarily **Floating Point Precision**.

Standard SGP4 libraries assume full 64-bit float precision. On a microcontroller payload, 32-bit floats aren't precise enough to handle Julian Dates (numbers like `2460678.12345`) while keeping second-level accuracy. Our initial tracks were off by thousands of kilometers!

**The Fix**: We refactored the satellite math to use **Integer Unix Timestamps** for the heavy lifting, only converting to small relative offsets when necessary. We verified this against NASA's own trackers, bringing our error down to a negligible **~50km** (on a global scale).

## 3. The Interface: Web & OLED
A tracker isn't fun if you don't know *what* it's tracking.
*   **OLED HUD**: We added a tiny 128x64 display on the base for immediate stats: Latitude, Longitude, and current satellite name.
*   **Web Dashboard**: Since the Pico 2W has WiFi, we built a hosted React dashboard. You can connect to the Orbigator from your phone to see a 3D visualization, change the tracked satellite (ISS, Hubble, Tiangong), and tweak settings live.

Orbigator CAD Render

## 4. Tuning the Mechanics
Physics caught up with us. Adding the "Argument of Vehicle" (AoV) assembly—complete with magnets and pennies for counterweights—introduced a pendulum effect. The motor would "wobble" as it tried to hold position.

We wrote a custom auto-tuning script (`tune_wobble.py`) to cycle through PID profiles. We landed on a stiff-but-smooth profile (`P=600, D=0`) and capped the speed. Now, it glides.

Mechanism Closeup

## 5. What's Next?
The mess of wires you see in the photos is "development aesthetic." It works, but it's fragile.

The next phase is purely hardware. I'm teaming up with **Anool** and **Kevin** to design a custom **Orbigator Control Board** that integrates the Pico, the RTC (Real Time Clock), and the motor drivers into a single, clean PCB.

The code is committed, the math is integer-perfect, and the motor is zeroed. Onward to proper PCBs!

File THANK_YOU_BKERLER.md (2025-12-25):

# Thank You Note for bkerler/sattracker

Hi @bkerler,

Thank you for creating and sharing the sattracker project! Your Plan13 implementation has been incredibly helpful for our Orbigator project.

## About Orbigator

We're building a physical orbital mechanics demonstrator using:
- Raspberry Pi Pico 2W (MicroPython)
- Two DYNAMIXEL XL330 servo motors
- OLED display + rotary encoder UI
- Real-time satellite tracking with your Plan13 algorithm

The device tracks satellites by moving a pointer around a globe, showing:
- Orbital mechanics (including elliptical orbits with Kepler's equation)
- Real-time position updates
- Support for both manual orbital parameters and TLE-based tracking

Your Plan13 implementation was perfect for MicroPython - much simpler and more memory-efficient than SGP4. We adapted it for the Pico 2W and it's working beautifully!

## Project Links

- GitHub: https://github.com/wyolum/orbigator
- Hardware: Pico 2W + DYNAMIXEL motors + 3D printed mounts

## Attribution

We've kept your original copyright and attribution in plan13.py. Thank you for making this available under an open license!

If you're interested, we'd love to collaborate or get your feedback on the project.

Best regards,
Justin (WyoLum)

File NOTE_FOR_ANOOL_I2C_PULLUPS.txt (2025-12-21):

IMPORTANT NOTE FOR ANOOL - I2C PULL-UP RESISTORS
================================================
Date: 2025-12-20

ISSUE DISCOVERED:
-----------------
The OLED display was experiencing glitching on the top line during operation.
Initially thought to be a software issue, but turned out to be hardware.

ROOT CAUSE:
-----------
Missing external I2C pull-up resistors on the shared I2C bus.

When using MULTIPLE I2C devices (OLED + RTC) on the same bus, the built-in 
pull-ups on individual modules are NOT sufficient. The bus needs stronger 
pull-ups to maintain signal integrity.

SOLUTION IMPLEMENTED:
---------------------
Added two 4.7kΩ pull-up resistors:
- R2: 4.7kΩ from SDA (GP4) to +3.3V
- R3: 4.7kΩ from SCL (GP5) to +3.3V

4. DS3231 RTC BACKUP POWER REQUIREMENT:
   ========================================
   The DS3231 RTC module REQUIRES backup power to maintain time when unplugged.
   
   OPTION 1: CR2032 Battery (Traditional)
   ---------------------------------------
   - Battery Type: CR2032 (3V lithium coin cell)
   - Backup Duration: 5-10 years
   - Footprint: Large (~20mm diameter battery holder)
   - Pros: Very long backup time, simple implementation
   - Cons: Large PCB footprint, requires periodic replacement
   
   OPTION 2: Supercapacitor (RECOMMENDED for Orbigator)
   -----------------------------------------------------
   - Component: 0.47F - 1F supercapacitor, 5.5V rated
   - Example: Panasonic EEC-series or equivalent
   - Backup Duration: Several days to weeks (sufficient for display piece)
   - Footprint: Small SMD package (similar to large electrolytic cap)
   - Charging Circuit: 47Ω resistor in series to limit inrush current
   
   Supercap Circuit:
   +3.3V ──┬── 47Ω ──┬── DS3231 BAT pin
           │         │
           │       [0.47F]
           │       Supercap
           │         │
          GND ──────┴── GND
   
   Pros: 
   - Much smaller PCB footprint
   - No battery replacement needed (lasts forever)
   - Environmentally friendly
   - Perfect for display piece that's usually powered
   
   Cons:
   - Shorter backup time than battery (but adequate for this use case)
   
   RECOMMENDATION: Use supercapacitor option for cleaner PCB design.

SUMMARY FOR PCB DESIGN:
-------------
- Touching wires with finger (adding capacitance) temporarily stabilized display
- Adding proper 4.7kΩ pull-ups completely fixed the glitching
- Display now updates smoothly at 1 Hz

CRITICAL FOR PCB DESIGN:
------------------------
When designing the Orbigator PCB, MUST include:
1. 4.7kΩ resistor from SDA to 3.3V
2. 4.7kΩ resistor from SCL to 3.3V

These are REQUIRED for reliable I2C communication with multiple devices.
Do NOT rely on module-internal pull-ups alone!

UPDATED DOCUMENTATION:
----------------------
- ORBIGATOR_CIRCUIT_DIAGRAM.txt now shows R2 and R3 pull-up resistors
- Critical connections section updated with I2C pull-up requirements

-- Justin

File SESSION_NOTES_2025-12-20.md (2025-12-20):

# Orbigator Session Notes - December 20, 2025

## Major Accomplishments Today

### 1. Fixed I2C Display Glitching ✅
- **Root Cause:** Missing external pull-up resistors on shared I2C bus (OLED + RTC)
- **Solution:** Added 4.7kΩ resistors on SDA (GP4) and SCL (GP5) to 3.3V
- **Documentation:** Created `NOTE_FOR_ANOOL_I2C_PULLUPS.txt` with critical PCB design requirements
- **Circuit Diagram:** Updated `ORBIGATOR_CIRCUIT_DIAGRAM.txt` with R2 and R3 pull-ups
- **Performance:** Reduced display update to 1Hz to minimize I2C traffic

### 2. Fixed Motor Control Issues ✅
- **Problem 1:** Motors not moving (positions stuck at 0.0, 0.0)
  - Fixed: Rate initialization bug when starting in state 3
  - Added startup initialization after `load_state()`

- **Problem 2:** EQX motor spinning continuously beyond 360°
  - Implemented `get_new_pos(current_pos, command_pos)` function
  - Preserves turn count in Extended Position Mode
  - Only applies incremental changes from wrapped positions

- **Problem 3:** Catch-up mechanism commanding extreme positions (773448°!)
  - Fixed `load_state()` catch-up to use `get_new_pos()` with modulo-wrapped targets
  - Motors now move smoothly without multi-revolution jumps

### 3. Motor Rate Calculations Clarified ✅
- **EQX Rate:** 360°/sidereal day (Earth rotation) + J2 precession (~5°/day)
- **Reference Frame:** Almost-ECI (Earth-Centered Inertial)
- **Position Wrapping:** Both motors use `get_new_pos()` to preserve turn count
- **User confirmed:** Need Earth rotation 360°/sidereal day, with modulo wrapping

### 4. Documentation Updates ✅
- Added `schematics/74HC126_pinout_diagram.png` - visual DIP pinout
- Added `schematics/74HC126_PINOUT.txt` - detailed text reference
- Added `schematics/dynamixel_xl330_pinout.png` - 3-pin connector diagram
- Added `schematics/dc_power_jack_pj007_drawing.png` - PJ-007 mechanical drawing
- Added `schematics/orbigator_pcb_layout_labeled.png` - labeled PCB layout
- Updated `README_DYNAMIXEL_MOTORS.md` with M2×8 screw info (AoV arm 5.25mm bracket)

## Current State

### Hardware
- ✅ Motors moving correctly with Extended Position Mode
- ✅ Display stable with I2C pull-ups
- ✅ RTC communication reliable with error handling
- ✅ All components wired and tested on breadboard

### Software (`orbigator.py`)
- ✅ Motor rates initialized properly at startup
- ✅ `get_new_pos()` function for turn-preserving position updates
- ✅ Catch-up mechanism working correctly
- ✅ Display updates at 1Hz
- ⚠️ User modified catch-up to add `% 360` to ensure positive positions (line 592-593)

### Mechanical Design
- 🔄 **Waiting for Anool's PCB feedback before 3D printing**
- Design complete with:
  - AoV motor mount (coral/copper) at orbital inclination
  - Penny counterweight cylinders on AoV arm
  - EQX ring gear for globe rotation
  - Integrated electronics base

## Key Implementation Details

### Extended Position Mode Wrapping
```python
def get_new_pos(current_pos, command_pos):
    """Preserves turn count, applies incremental change"""
    turns, pos = divmod(current_pos, 360)
    change = command_pos - pos
    return turns * 360 + pos + change
```

**Usage:**
- Read current position from motor
- Calculate target position modulo 360
- Use `get_new_pos()` to preserve turn count
- Command the result

### I2C Pull-up Requirements
- **Critical for PCB:** 4.7kΩ from SDA to 3.3V, 4.7kΩ from SCL to 3.3V
- Required when multiple I2C devices share the bus
- Individual module pull-ups are NOT sufficient

### Power Distribution
- Single 5V supply for Dynamixel motors
- Pico 2 powered via VSYS (Pin 39) from same 5V supply
- Common ground for all components

## Pending Items

1. **Waiting for Anool:**
   - PCB design feedback
   - After approval: 3D print mechanical assembly

2. **Future Enhancements:**
   - Test full assembly with globe installed
   - Calibrate gear ratios and motion rates
   - Verify orbital mechanics accuracy

## Important Files to Reference

- `micropython/orbigator.py` - Main control code (motors working!)
- `NOTE_FOR_ANOOL_I2C_PULLUPS.txt` - Critical PCB requirements
- `ORBIGATOR_CIRCUIT_DIAGRAM.txt` - Complete wiring with pull-ups
- `README_DYNAMIXEL_MOTORS.md` - Motor setup and mounting hardware
- `schematics/` - All component diagrams and PCB layout

## Next Session TODO

- [ ] Review any feedback from Anool on PCB design
- [ ] Assist with 3D print preparation if needed
- [ ] Test any remaining motor control edge cases
- [ ] Document final assembly procedures

---
**Session Summary:** Major debugging session! Fixed I2C glitching with pull-ups, resolved motor position wrapping issues, and clarified EQX rate calculations. Hardware is stable, software is solid, waiting on PCB feedback before final assembly.

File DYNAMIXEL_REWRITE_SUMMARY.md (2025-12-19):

# Orbigator Dynamixel Rewrite - Code Summary

## Files Created/Modified

### New Files

1. **`dynamixel_motor.py`** (118 lines)
   - Motor abstraction layer with gear ratio support
   - Handles conversion between output degrees (globe position) and motor ticks
   - Automatic position tracking and baseline reading on init

2. **`test_dynamixel_motor.py`** (189 lines)
   - Comprehensive unit test suite
   - Tests initialization, absolute positioning, relative movement, continuous rotation
   - Verifies gear ratio calculations for EQX motor

3. **`orbigator_stepper_motors.py`** (800 lines)
   - Backup of original stepper motor version
   - Rollback available if needed

### Modified Files

1. **`orbigator.py`** (562 lines, down from 800)
   - **Removed:** ~400 lines of stepper motor control code
   - **Added:** Dynamixel motor integration
   - **Simplified:** Motion control logic (motors handle acceleration internally)
   - **Maintained:** Same state machine, UI, and persistence logic

## Key Changes

### Motor Control

**Before (Stepper Motors):**
```python
# Complex step-by-step control
lan_move_steps(steps)
aov_move_steps(steps)
# S-curve acceleration profiles
# Step counting and wrap-around logic
```

**After (Dynamixel):**
```python
# Simple angle-based control
lan_motor.set_angle_degrees(angle)
aov_motor.set_angle_degrees(angle)
# Motors handle acceleration automatically
```

### Gear Ratio Handling

**EQX Motor:**
- 11T drive gear → 120T ring gear (ratio ≈ 10.909:1)
- When you set globe to 45°, motor rotates to ~490.9°
- All position tracking is in **globe degrees**, not motor degrees

**AoV Motor:**
- Direct drive (ratio = 1.0)
- Motor degrees = globe degrees

### Code Reduction

| Metric | Before | After | Change |
|---|---|---|---|
| Total lines | 800 | 562 | -238 (-30%) |
| Motor control | ~400 | ~120 | -280 (-70%) |
| Complexity | High | Low | Simplified |

## Benefits

1. **Simpler Code:** Removed complex stepper timing and acceleration code
2. **Faster Response:** Motors move immediately, no step-by-step delays
3. **Smoother Motion:** Built-in acceleration/deceleration profiles
4. **More Accurate:** No step accumulation errors
5. **Continuous Rotation:** Extended Position Mode supports unlimited rotation
6. **Position Persistence:** Motors remember position across power cycles

## Verification Status

- [x] Implementation complete
- [ ] Unit tests (to be run on hardware)
- [ ] Manual verification (to be performed)
- [ ] 24-hour stability test (pending)

## Next Steps

1. Upload files to Pico
2. Run `test_dynamixel_motor.py` to verify motor abstraction
3. Run `orbigator.py` and test all 4 states
4. Verify persistence and catch-up logic
5. Monitor for 24 hours

## Rollback Procedure

If issues arise:
```bash
cd /home/justin/code/orbigator/micropython
cp orbigator_stepper_motors.py orbigator.py
# Reconnect stepper motors
# Reboot Pico
```

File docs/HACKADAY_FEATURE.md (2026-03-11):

# 📰 Hackaday Feature: The Orbigator

The Orbigator was officially featured on Hackaday on March 8, 2026. This document preserves the article and key community discussion for the project's historical record.

---

## Article: "The Orbigator: Satellite Tracking With Style"
**Published**: March 8, 2026  
**Source**: [Hackaday](https://hackaday.com/2026/03/08/the-orbigator-satellite-tracking-with-style/)

> What hardware hacker doesn’t have a soft spot for transparent cases? While they may have fallen out of mainstream favor, they have an undeniable appeal to anyone with an interest in electronic or mechanical devices. Which is why the Orbigator built by **[wyojustin]** stands out among similar desktop orbital trackers we’ve seen.
>
> Conceptually, it’s very similar to the International Space Station tracking lamp that [Will Dana] built in 2025. In fact, [wyojustin] cites it specifically as one of the inspirations for this project. But unlike that build, which saw a small model of the ISS moving across the surface of the globe, a transparent globe is rotated around the internal mechanism. This not only looks gorgeous, but solves a key problem in [Will]’s design — that is, there’s no trailing servo wiring that needs to be kept track of.
>
> For anyone who wants an Orbigator of their own, [wyojustin] has done a fantastic job of documenting the hardware and software aspects of the build, and all the relevant files are available in the project’s GitHub repository.
>
> The 3D printable components have been created with OpenSCAD, the firmware responsible for calculating the current position of the ISS on the Raspberry Pi Pico 2 is written in MicroPython, and the PCB was designed in KiCad. Incidentally, we noticed that Hackaday alum [Anool Mahidharia] appears to have been lending a hand with the board design.
>
> As much as we love these polished orbital trackers, we’ve seen far more approachable builds if you don’t need something so elaborate. If you’re more interested in keeping an eye out for planes and can get your hands on a pan-and-tilt security camera, it’s even easier.

---

*Preserved for the Orbigator historical record. Original article by [Hackaday Staff](https://hackaday.com/2026/03/08/the-orbigator-satellite-tracking-with-style/).*

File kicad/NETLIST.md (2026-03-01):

# Orbigator Netlist

This netlist describes all electrical connections in the Orbigator circuit.

## Power Nets

### +5V (External Supply)
- J1 (Barrel Jack) Pin 1
- M1 (DYNAMIXEL 1) Pin 2 (VDD)
- M2 (DYNAMIXEL 2) Pin 2 (VDD)
- R1 (10kΩ) Pin 1

### +3.3V (from Pico)
- U1 (Pico 2) Pin 36 (3V3_OUT)
- U2 (74HC126) Pin 14 (VCC)
- DISP1 (OLED) VCC
- RTC1 (DS3231) VCC
- ENC1 (Encoder) VCC
- R2 (4.7kΩ) Pin 1
- R3 (4.7kΩ) Pin 1

### GND (Common Ground)
- J1 (Barrel Jack) Pin 2
- U1 (Pico 2) Pins 3, 38
- U2 (74HC126) Pin 7
- M1 (DYNAMIXEL 1) Pin 1
- M2 (DYNAMIXEL 2) Pin 1
- DISP1 (OLED) GND
- RTC1 (DS3231) GND
- ENC1 (Encoder) GND

## Signal Nets

### UART_TX (Pico → Buffer → Motors)
- U1 (Pico 2) Pin 1 (GP0)
- U2 (74HC126) Pin 2 (1A)

### UART_RX (Motors → Pico)
- U1 (Pico 2) Pin 2 (GP1)
- DATA_BUS (direct connection)

### DIR_PIN (Buffer Control)
- U1 (Pico 2) Pin 4 (GP2)
- U2 (74HC126) Pin 1 (1OE)

### DATA_BUS (Half-Duplex DYNAMIXEL)
- U2 (74HC126) Pin 3 (1Y)
- M1 (DYNAMIXEL 1) Pin 3 (DATA)
- M2 (DYNAMIXEL 2) Pin 3 (DATA)
- R1 (10kΩ) Pin 2 (pull-up to +5V)
- J2 (DYNAMIXEL Connector) Pin 3

### I2C_SDA (Shared Bus)
- U1 (Pico 2) Pin 6 (GP4)
- DISP1 (OLED) SDA
- RTC1 (DS3231) SDA
- R2 (4.7kΩ) Pin 2 (pull-up to +3.3V)

### I2C_SCL (Shared Bus)
- U1 (Pico 2) Pin 7 (GP5)
- DISP1 (OLED) SCL
- RTC1 (DS3231) SCL
- R3 (4.7kΩ) Pin 2 (pull-up to +3.3V)

### ENC_A (Encoder Channel A)
- U1 (Pico 2) Pin 9 (GP6)
- ENC1 (Encoder) Pin A
- J3 (Encoder Connector) Pin 1

### ENC_B (Encoder Channel B)
- U1 (Pico 2) Pin 10 (GP7)
- ENC1 (Encoder) Pin B
- J3 (Encoder Connector) Pin 2

### ENC_SW (Encoder Switch)
- U1 (Pico 2) Pin 11 (GP8)
- ENC1 (Encoder) Pin SW
- J3 (Encoder Connector) Pin 3

### RTC_BAT (Backup Power)
- RTC1 (DS3231) BAT pin
- BAT1 (CR2032) Positive pin

## Net Summary

| Net Name | Connection Count | Notes |
|---|---|---|
| +5V | 5 | External supply, 4-5A required |
| +3.3V | 9 | From Pico, low current |
| GND | 13 | Common ground |
| DATA_BUS | 5 | Half-duplex, needs 10kΩ pull-up |
| I2C_SDA | 4 | Multi-device bus, needs 4.7kΩ pull-up |
| I2C_SCL | 4 | Multi-device bus, needs 4.7kΩ pull-up |
| UART_TX | 2 | Pico to buffer |
| UART_RX | 2 | Motors to Pico |
| DIR_PIN | 2 | Buffer direction control |
| ENC_A | 3 | Encoder channel A |
| ENC_B | 3 | Encoder channel B |
| ENC_SW | 3 | Encoder button |
| RTC_BAT | 2 | Battery backup (CR2032) |

## Design Rules

### Trace Widths
- Power (+5V, GND): 1.0mm minimum (motor current)
- +3.3V: 0.5mm minimum
- Signal traces: 0.25mm minimum
- I2C, UART: 0.25mm (short traces, low speed)

### Clearances
- Minimum clearance: 0.2mm
- Power to signal: 0.3mm recommended

### Via Specifications
- Standard via: 0.8mm diameter, 0.4mm drill
- Power vias: Multiple vias for high current paths

## Layout Recommendations

1. **Keep I2C traces short** - Minimize capacitance
2. **Place pull-up resistors near devices** - R2/R3 near Pico, R1 near motors
3. **Separate power planes** - Keep 5V and 3.3V domains clear
4. **Future Improvement** - Add decoupling capacitors (0.1µF) near ICs in next revision.
5. **Motor connector placement** - Easy cable routing to motors
6. **Encoder connector** - Accessible for user interaction

## Testing Points

Recommended test points for debugging:
- TP1: +5V
- TP2: +3.3V
- TP3: GND
- TP4: DATA_BUS
- TP5: I2C_SDA
- TP6: I2C_SCL
- TP7: UART_TX
- TP8: UART_RX

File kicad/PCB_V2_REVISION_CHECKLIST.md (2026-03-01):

# Orbigator PCB Revision 2 Checklist

This checklist outlines the changes required for the next hardware "spin" (Revision 2), focusing on SMD migration and a robust dual-power supply implementation.

## 1. SMD Component Migration
Replace existing through-hole (THT) and breakout modules with surface-mount (SMD) equivalents.

- [ ] **RTC (U3)**: Switch from the `Fermion DS3232` breakout to a standalone **DS3232MZ+** (SOIC-8) or **DS3232SN#** (SOIC-20).
    - *Note*: This integrates the crystal and provides ±2ppm accuracy.
- [ ] **74HC126 (Buffer)**: Switch from `DIP-14` to **SOIC-14** (e.g., 74HC126D).
- [ ] **Resistors (R1-R3)**: Switch from `Axial THT` to **0805** or **0603** SMD packages.
- [ ] **Battery (BAT1)**: Ensure a footprint for a small SMD coin cell holder (e.g., **CR1220** or **CR1225**) is included to replace the current off-board battery wiring.

## 2. Robust Dual-Power Supply (VBUS / External)
Implement the P-FET "ideal diode" circuit from the **Pico 2 Datasheet (Figure 9)** to manage power from both USB (VBUS) and the Barrel Jack (VEXT).

- [ ] **J1 (Barrel Jack)**: Retain the **5.5mm x 2.1mm Through-Hole** jack for mechanical strength.
- [ ] **P-FET (Q1)**: Add a **DMG2305UX** (SOT-23) P-channel MOSFET.
    - **Source**: Connected to the External 5V supply (from Barrel Jack).
    - **Drain**: Connected to the Pico **VSYS** pin.
    - **Gate**: Connected to Pico **VBUS** (Pin 40).
- [ ] **Schottky Diode (D1)**: Add a secondary Schottky diode (e.g., **B130**) in parallel with the P-FET (Source to Drain) to protect against slow VBUS transitions.
- [ ] **Protection**: Ensure VEXT doesn't exceed 5.5V to protect the Pico VSYS input.

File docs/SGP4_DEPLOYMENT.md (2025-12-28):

# SGP4 Integration - Deployment Summary

## ✅ Successfully Deployed to Pico 2W

All SGP4 satellite tracking files have been uploaded and verified on your Pico 2W.

### Files Deployed

**New Files:**
- ✅ `satellite_catalog.py` (914 bytes) - 4 satellites: ISS, Hubble, Tiangong, Starlink
- ✅ `tle_cache.json` (471 bytes) - Pre-cached TLEs for ISS and Hubble

**Updated Files:**
- ✅ `modes.py` (31,454 bytes) - Added SGP4Mode class
- ✅ `orb_utils.py` (14,654 bytes) - Added GMST and TLE utilities

**Existing Files (Preserved):**
- ✅ `sgp4.py` - SGP4 propagator
- ✅ `tle_fetch.py` - TLE fetching via WiFi
- ✅ `orbigator.py` - Main application (unchanged)

### Verification Results

```
✓ Satellite catalog: 4 satellites loaded
✓ TLE cache: 2 satellites (ISS, Hubble)
✓ All files uploaded successfully
✓ No syntax errors
```

### How to Test

**Power on your Orbigator and:**

1. **Navigate to SGP4 Mode:**
   - Main Menu → "Track Satellite" (2nd item)

2. **Select Satellite:**
   - Rotate encoder: ISS → Hubble → Tiangong → Starlink
   - Watch display show satellite name and TLE age

3. **Start Tracking:**
   - Press encoder button
   - Display changes to "TRACKING" mode
   - Motors move to satellite position
   - Lat/Lon/Alt update in real-time

4. **Verify Baseline:**
   - Press Back to return to menu
   - Select "Orbit!" mode
   - Confirm original functionality works

### Expected Behavior

**ISS Tracking:**
- Latitude: -51.6° to +51.6° (oscillating)
- Longitude: Continuously increasing ~4°/minute
- Altitude: ~400-420 km
- Motors follow satellite position

**TLE Updates:**
- Press Confirm button to fetch fresh TLE
- WiFi connects automatically
- TLE age resets to "0h"

### Troubleshooting

If you encounter issues:

1. **"No Satellite Data"** - TLE cache missing, press Confirm to fetch
2. **Motors not moving** - Check tracking mode is active (press encoder)
3. **WiFi fetch fails** - Check `wifi_config.json` credentials
4. **Baseline broken** - All original modes preserved, should work identically

---

**🎉 SGP4 Integration Complete!**

Your Orbigator can now track real satellites in real-time using accurate SGP4 propagation.

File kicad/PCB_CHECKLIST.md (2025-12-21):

# PCB Design Checklist for Orbigator

Use this checklist to ensure all critical design elements are included.

## Pre-Layout

- [ ] Review schematic for errors
- [ ] Run ERC (Electrical Rules Check) - must pass with 0 errors
- [ ] Verify all footprints assigned
- [ ] Check component values match BOM
- [ ] Verify I2C pull-ups (R2, R3) are 4.7kΩ to +3.3V
- [ ] Verify DYNAMIXEL pull-up (R1) is 10kΩ to +5V
- [ ] Verify supercap circuit (C1, R4) is correct

## Component Placement

### Power Components
- [ ] Place Pico 2 (U1) in center of board
- [ ] Place 74HC126 (U2) near Pico GP0/GP1/GP2
- [ ] Place decoupling caps (C2, C3) within 5mm of ICs
- [ ] Place power input (J1) on edge

### I2C Devices
- [ ] Group OLED (DISP1) and RTC (RTC1) near Pico GP4/GP5
- [ ] Place I2C pull-ups (R2, R3) near Pico
- [ ] Keep I2C traces < 50mm if possible

### Connectors
- [ ] Place motor connectors (M1, M2, J2) on accessible edge
- [ ] Place encoder connector (J3) on accessible edge
- [ ] Ensure all connectors face outward for easy cable access

### Special Components
- [ ] Place supercap (C1) near RTC
- [ ] Place charging resistor (R4) between +3.3V and C1
- [ ] Ensure polarity marking on C1 is visible

## Routing

### Power Traces (Priority 1)
- [ ] Route +5V with 1.0mm traces (motor current)
- [ ] Route +3.3V with 0.5mm traces
- [ ] Create ground pour on bottom layer
- [ ] Add multiple vias for ground connections
- [ ] Verify power traces have no bottlenecks

### Critical Signals (Priority 2)
- [ ] Route I2C_SDA and I2C_SCL together, keep short
- [ ] Route UART_TX, UART_RX, DIR_PIN with 0.25mm traces
- [ ] Route DATA_BUS with 0.25mm trace
- [ ] Keep UART and DATA_BUS traces < 100mm

### Other Signals (Priority 3)
- [ ] Route encoder signals (ENC_A, ENC_B, ENC_SW)
- [ ] Route RTC_BAT to supercap

### Design Rules
- [ ] All traces meet minimum width (0.25mm)
- [ ] All clearances meet minimum (0.2mm)
- [ ] No acute angles in traces (use 45° or curved)
- [ ] No vias in pads (unless intentional thermal vias)

## Silkscreen

- [ ] All component references visible and readable
- [ ] Polarity markings on C1 (supercap)
- [ ] Pin 1 indicators on ICs
- [ ] Connector pin labels (especially J2, J3)
- [ ] Board name and version visible
- [ ] Company name (WyoLum) visible
- [ ] Critical warnings (e.g., "5V ONLY" near J1)

## Design Rule Check (DRC)

- [ ] Run DRC - must pass with 0 errors
- [ ] Check for unconnected nets
- [ ] Check for overlapping components
- [ ] Check for traces too close to board edge
- [ ] Check for missing copper in power nets

## Final Checks

- [ ] Board outline is correct (70mm × 55mm after rotation)
- [ ] Mounting holes are correct (M3, centered pattern)
- [ ] All components within board outline
- [ ] No silkscreen over pads
- [ ] No silkscreen on Edge.Cuts layer
- [ ] Ground pour has no isolated islands
- [ ] Test points added for debugging (optional but recommended)

## Pre-Fabrication

- [ ] Generate Gerber files
- [ ] Generate drill files
- [ ] Verify Gerber files in viewer
- [ ] Export BOM (CSV format)
- [ ] Export pick-and-place file (if using assembly service)
- [ ] Create assembly drawing (PDF)
- [ ] Zip all manufacturing files

## Manufacturing Notes

**PCB Specifications:**
- 2-layer board
- 1.6mm thickness
- 1oz copper
- HASL or ENIG finish
- Green solder mask (or your preference)
- White silkscreen

**Recommended Manufacturers:**
- JLCPCB (cheap, fast)
- PCBWay (good quality)
- OSH Park (USA, purple boards)

**Typical Lead Time:** 5-10 days + shipping

## Assembly Notes

**Assembly Order:**
1. Solder SMD components first (if any)
2. Solder through-hole resistors and capacitors
3. Solder ICs (74HC126)
4. Solder connectors
5. Solder Pico 2 (use headers or direct solder)
6. Install supercap (C1) - watch polarity!
7. Test continuity before applying power

**Testing:**
1. Visual inspection
2. Continuity test (power rails, ground)
3. Power-on test (measure voltages)
4. I2C bus test (scan for devices)
5. Motor communication test
6. Full system test

---

**Questions?** Refer to:
- `SCHEMATIC_GUIDE.md` - Schematic creation steps
- `bom/BOM.md` - Component specifications
- `NETLIST.md` - Connection details
- `NOTE_FOR_ANOOL_I2C_PULLUPS.txt` - Critical design notes

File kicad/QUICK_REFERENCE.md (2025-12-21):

# Quick Reference Card - Orbigator PCB

## Critical Components (Don't Forget!)

### I2C Pull-ups ⚠️ CRITICAL
```
R2: 4.7kΩ from SDA (GP4) to +3.3V
R3: 4.7kΩ from SCL (GP5) to +3.3V
```
**Without these, OLED will glitch and RTC will fail!**

### DYNAMIXEL Pull-up ⚠️ CRITICAL
```
R1: 10kΩ from DATA bus to +5V (NOT +3.3V!)
```

### RTC Backup Power
```
R4: 47Ω from +3.3V to supercap
C1: 0.47F supercap to GND (watch polarity!)
```

## Pin Connections Quick Reference

### Raspberry Pi Pico 2 (U1)
| Pin | GPIO | Function | Connects To |
|-----|---|---|---|
| 1 | GP0 | UART TX | 74HC126 Pin 2 |
| 2 | GP1 | UART RX | DATA_BUS |
| 4 | GP2 | DIR | 74HC126 Pin 1 |
| 6 | GP4 | I2C SDA | OLED, RTC, R2 |
| 7 | GP5 | I2C SCL | OLED, RTC, R3 |
| 9 | GP6 | ENC A | Encoder A |
| 10 | GP7 | ENC B | Encoder B |
| 11 | GP8 | ENC SW | Encoder Switch |
| 36 | 3V3_OUT | Power | All 3.3V devices |
| 3, 38 | GND | Ground | Common ground |

### 74HC126 Buffer (U2)
| Pin | Function | Connects To |
|-----|---|---|
| 1 | 1OE | Pico GP2 |
| 2 | 1A | Pico GP0 |
| 3 | 1Y | DATA_BUS |
| 7 | GND | Ground |
| 14 | VCC | +3.3V |

### Power Distribution
```
+5V:  J1 → M1, M2, R1
+3.3V: Pico Pin 36 → U2, DISP1, RTC1, ENC1, R2, R3, R4
GND: Common to all
```

## Board Dimensions
- **Size**: 55mm × 70mm (rotated 90° on A4 sheet)
- **Mounting Holes**: 4× M3 (3.2mm diameter)
- **Hole Positions**: 
  - (75.5, 134), (75.5, 163)
  - (134.5, 134), (134.5, 163)

## Trace Width Guide
| Net | Width | Notes |
|-----|---|---|
| +5V | 1.0mm+ | Motor power |
| +3.3V | 0.5mm | Low current |
| GND | Pour | Bottom layer |
| Signals | 0.25mm | Default |

## Component Placement Tips
1. **Pico in center** - everything radiates from here
2. **I2C devices grouped** - near GP4/GP5
3. **Buffer near Pico** - short UART traces
4. **Connectors on edges** - easy cable access
5. **Decoupling caps close** - within 5mm of ICs

## Common Mistakes to Avoid
- ❌ I2C pull-ups to +5V (should be +3.3V!)
- ❌ DYNAMIXEL pull-up to +3.3V (should be +5V!)
- ❌ Supercap polarity reversed
- ❌ Forgetting decoupling capacitors
- ❌ Traces too thin for motor power
- ❌ I2C traces too long

## Testing Checklist
1. ✓ Visual inspection
2. ✓ Continuity: +5V, +3.3V, GND
3. ✓ No shorts between power rails
4. ✓ Measure voltages before connecting devices
5. ✓ I2C scan (should find 0x3C and 0x68)
6. ✓ Motor communication test

## Emergency Contacts
- **Schematic**: `kicad/SCHEMATIC_GUIDE.md`
- **BOM**: `kicad/bom/BOM.md`
- **Netlist**: `kicad/NETLIST.md`
- **Critical Notes**: `NOTE_FOR_ANOOL_I2C_PULLUPS.txt`

---
**Remember**: When in doubt, check the documentation! 📚

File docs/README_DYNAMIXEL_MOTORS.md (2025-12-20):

# 🎉 DYNAMIXEL MOTORS - START HERE! 🎉

## ⚡ SERVO CHOICE: XL330-M288-T

**Selected Model:** DYNAMIXEL XL330-M288-T
**Specifications:**
- Protocol 2.0 communication
- 0.52 N·m stall torque @ 5V
- 288° range in Position Control Mode
- Unlimited rotation in Extended Position Mode (Mode 4)
- Compact size: 24mm × 36mm × 27mm
- Metal horn with M2 mounting holes

---

## Quick Start Guide for Orbigator DYNAMIXEL Integration

### 📋 **Step 1: Review Wiring Documentation**

**MAIN REFERENCE:** `ORBIGATOR_COMPLETE_WIRING.txt`
- Complete pin assignments for entire system
- All connections clearly documented
- Power distribution diagram
- No stepper motor connections (clean DYNAMIXEL design)

**Additional References:**
- `DYNAMIXEL_WIRING_DIAGRAM.txt` - ASCII circuit diagram
- `DYNAMIXEL_Connection_with_74HC126.md` - Detailed guide with code
- `DYNAMIXEL_Quick_Reference.md` - One-page cheat sheet

### 🔧 **Step 2: Configure Servo IDs**

**IMPORTANT:** Before wiring both servos together, set their IDs!

**Script Location:** `micropython/dynamixel_setup.py`

**Quick Setup Method:**
1. Upload `dynamixel_setup.py` to your Pico 2
2. Wire up **ONE servo at a time** with the 74HC126 circuit
3. Run the script and use the guided setup:
   ```python
   setup_orbigator_servos()
   ```
4. Follow prompts to set:
   - First servo → ID=1 (EQX Motor)
   - Second servo → ID=2 (AoV Motor - Argument of Vehicle)

**Alternative - Interactive Menu:**
```python
main()  # Then select option 3 to change IDs
```

### ⚡ **Step 3: Wire Everything**

Follow `ORBIGATOR_COMPLETE_WIRING.txt` exactly:

**Key Connections:**
- GP0 → 74HC126 Pin 2 (TX)
- GP1 → DATA BUS (RX)
- GP2 → 74HC126 Pin 1 (Direction Control)
- 10kΩ pull-up on DATA line to 5V
- Both servos share DATA BUS (daisy-chain)
- External 5V 4-5A power supply for servos

**Critical Notes:**
- ✅ Common ground for ALL components
- ✅ DO NOT power servos from Pico
- ✅ Each servo must have unique ID (1 and 2)

### 🧪 **Step 4: Test Communication**

Use `dynamixel_setup.py` to verify:
```python
# Scan for both servos
scan_servos()

# Should find ID 1 and 2
ping(1)  # EQX Motor
ping(2)  # AoV Motor

# Test movement
set_torque(1, True)
set_position(1, 2048)  # Center position
```

### 🚀 **Step 5: Integrate with Orbigator**

Update `orbigator.py` to use DYNAMIXEL instead of steppers:
- Replace `lan_move_steps()` with DYNAMIXEL position commands
- Replace `aov_move_steps()` with DYNAMIXEL position commands
- Use servo feedback for accurate position tracking

### 🔩 **Mounting Hardware**

Each XL330-M288-T motor includes:
- **10× M2×8 screws** (PHS TAP type)
- **6× M2×6 screws** (PHS TAP type - for horn accessories)

**For Orbigator mounting:**
- **Motor body mounting:** Use M2×8 screws
  - AoV arm bracket thickness: 5.25mm
  - Screws mount from back of bracket into motor body
  - Slight chamfer at hole entrance helps guide screws
  - Screw fully until threads engage (don't stop at the chamfer!)
- **Horn mounting:** M2×6 screws work for horn accessories
- **Note:** For Orbigator, only M2×8 screws are needed for motor mounting

### 📦 **Parts Checklist**

Before you start, verify you have:
- ✅ 2× DYNAMIXEL XL330-M288-T servos
- ✅ 1× SN74HC126N IC
- ✅ 1× 10kΩ resistor
- ✅ 1× 5V 4-5A power supply
- ✅ Jumper wires
- ✅ Breadboard or PCB

### 🎯 **Servo Assignments**

| Servo ID | Motor Type | Function |
|---|---|---|
| 1 | EQX Motor | Equator crossing |
| 2 | AoV Motor | Argument of Vehicle (0°=equator↑, 90°=max lat, 180°=equator↓, 270°=min lat) |

### 📞 **Need Help?**

All documentation is in the `orbigator` directory:
- Wiring diagrams
- Setup scripts
- Code examples
- Troubleshooting guides

**Good luck with your DYNAMIXEL upgrade!** 🚀

---
*Created: December 7, 2025*
*When motors arrive, start with ORBIGATOR_COMPLETE_WIRING.txt*

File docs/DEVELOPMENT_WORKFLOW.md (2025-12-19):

# Development Workflow - Orbigator Project

## CRITICAL: MicroPython File Updates

**When editing MicroPython library/utility files:**

⚠️ **ALWAYS remind the user to upload updated files to the Pico 2!**

Changes to library files do NOT take effect until uploaded to the device.

### Files That Require Upload

Library and utility `.py` files in the `micropython/` directory:
- `dynamixel_motor.py` - Motor abstraction layer ⚠️ **REQUIRES UPLOAD**
- `dynamixel_extended_utils.py` - Low-level motor control ⚠️ **REQUIRES UPLOAD**
- `dynamixel_setup.py` - Motor configuration utilities
- `ds3231.py` - RTC driver
- `ssd1306.py` / `sh1106.py` - OLED drivers

### Files That Do NOT Require Upload

- `orbigator.py` - Main control code (runs from laptop, not Pico)

### Upload Methods

**Option 1: Using Thonny**
1. Connect Pico 2 via USB
2. Open Thonny IDE
3. Open the file on your computer
4. File → Save As → Raspberry Pi Pico
5. Save to the root directory

**Option 2: Using mpremote**
```bash
mpremote cp micropython/orbigator.py :orbigator.py
mpremote cp micropython/dynamixel_motor.py :dynamixel_motor.py
```

### Reminder Template

When editing MicroPython files, use this reminder:

```
📤 REMINDER: Upload Updated Files to Pico 2

I've made changes to the following MicroPython files:
- ✅ micropython/[filename].py - [brief description of changes]

To update your Pico 2:
1. Connect Pico 2 via USB
2. Use Thonny or mpremote to upload:
   - micropython/[filename].py

Changes won't take effect until you upload the updated files!
```

## AI Assistant Instructions

**For Claude and future AI assistants:**

When you edit any `.py` file in the `micropython/` directory:
1. Complete your edits
2. ALWAYS include the upload reminder in your response
3. List all modified MicroPython files
4. Provide clear upload instructions

This is critical because the user is working with embedded hardware where code changes require manual file transfer.

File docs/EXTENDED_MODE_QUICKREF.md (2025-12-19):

# Extended Position Mode - Quick Reference

## 🚀 Quick Start

### One-Time Setup
```python
from dynamixel_extended_utils import set_extended_mode

set_extended_mode(1)  # EQX motor
set_extended_mode(2)  # AoV motor
```

### Every Boot
```python
from dynamixel_extended_utils import orbigator_init, write_dword

# Read current positions (CRITICAL!)
lan_pos, aov_pos = orbigator_init()

# Now safe to move motors
write_dword(1, 116, lan_pos + 1000)  # Move EQX forward
write_dword(2, 116, aov_pos + 2000)  # Move AoV forward
```

## 📋 Key Points

✅ **Set Mode 4 once** - Never switch back  
✅ **Read position on boot** - Prevents jumps  
✅ **Ignore overflow** - 62+ years at 1°/10sec  
✅ **Optional reset** - Use `clear_multi_turn()` if needed  

## 🔧 Common Functions

| Function | Purpose |
|---|---|
| `set_extended_mode(id)` | One-time Mode 4 setup |
| `orbigator_init()` | Boot routine - read positions |
| `read_present_position(id)` | Get current position |
| `write_dword(id, 116, pos)` | Set goal position |
| `clear_multi_turn(id)` | Reset counter (optional) |

## ⚠️ Critical Rule

**NEVER** send a goal position without reading the current position first on boot!

```python
# ❌ WRONG - Motor will jump!
write_dword(1, 116, 0)

# ✅ CORRECT - Motor stays smooth
current = read_present_position(1)
write_dword(1, 116, current + offset)
```

## 📚 Full Documentation

See [`EXTENDED_POSITION_MODE_GUIDE.md`](file:///home/justin/code/orbigator/EXTENDED_POSITION_MODE_GUIDE.md) for complete details.

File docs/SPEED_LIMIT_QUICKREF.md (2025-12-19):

# Speed Limit Quick Reference

## Current Settings

In `orbigator.py`, after motor initialization:
```python
aov_motor.set_speed_limit(velocity=150)  # AoV (pointer arm)
eqx_motor.set_speed_limit(velocity=100)  # LAN (orbital plane)
```

## How It Works

**Profile Velocity** controls maximum motor speed:
- **0** = No limit (FAST! Not recommended)
- **50-100** = Moderate speed (good for testing)
- **100-200** = Slow, safe speed (recommended for display)
- **200+** = Very slow (may be too slow for real-time simulation)

**Remember**: Higher values = SLOWER movement

## Adjusting Speed

### Make It Slower (Safer)
Increase the velocity value:
```python
aov_motor.set_speed_limit(velocity=200)  # Very slow
eqx_motor.set_speed_limit(velocity=150)  # Slower
```

### Make It Faster (More Responsive)
Decrease the velocity value:
```python
aov_motor.set_speed_limit(velocity=80)   # Faster
eqx_motor.set_speed_limit(velocity=50)   # Much faster
```

### Remove Speed Limit (Not Recommended!)
```python
aov_motor.set_speed_limit(velocity=0)    # No limit - FAST!
```

## Recommended Values

### For Display/Demo
```python
aov_motor.set_speed_limit(velocity=150)  # Slow, visible motion
eqx_motor.set_speed_limit(velocity=100)  # Moderate
```

### For Testing
```python
aov_motor.set_speed_limit(velocity=80)   # Faster for quick tests
eqx_motor.set_speed_limit(velocity=60)   # Faster
```

### For Time-Lapse
```python
aov_motor.set_speed_limit(velocity=50)   # Fast for time-lapse
eqx_motor.set_speed_limit(velocity=30)   # Fast
```

## Notes

- Speed limits are set in RAM, not EEPROM (reset on power cycle)
- Changes take effect immediately on next movement command
- Each motor can have different speed limits
- EQX motor is already slower due to 10.909:1 gearing
- AoV motor should generally be slower than LAN for smooth, visible motion

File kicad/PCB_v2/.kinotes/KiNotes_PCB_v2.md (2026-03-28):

# **PCB_v2 - Design Notes**

## **Overview**
<!-- Brief description of the PCB project -->

## **Schematic Notes**
<!-- Key circuit blocks, design rationale -->

## **Layout Considerations**
<!-- Layer stackup, impedance, keep-outs -->

## **Component Notes**
<!-- Click on designators like R1, C5, U3 to highlight on PCB -->

## **Power Distribution**
<!-- Power rails, decoupling strategy -->

## **Signal Integrity**
<!-- Critical nets, routing constraints -->

## **References**
<!-- Datasheets, application notes, calculations -->

---
*KiNotes - PCBtools.xyz*

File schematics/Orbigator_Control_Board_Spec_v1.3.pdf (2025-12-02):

# Orbigator Control Board – Hardware Specification

(v1.3)

## Overview

Compact dual-stepper controller for the Orbigator project.
Manages two axes: RAAN (Right Ascension of Ascending Node) and Mean Anomaly (MA).
Built around a Raspberry Pi Pico 2 and two Pololu DRV8834 stepper-driver carriers.
Includes a combined 1.3″ OLED (SSD1106, 128×64) + rotary encoder module, and a DS3231 RTC. Single-supply operation from a 5 V DC barrel jack.

## Primary Bill of Materials

Qty | Item | Notes
1 | Raspberry Pi Pico 2 (RP2350) | 3.3 V logic; USB-C optional
2 | Pololu DRV8834 Low-Voltage Stepper Carriers | White board; 2.5–10.8 V VMOT
1 | SY28STH32-067A Stepper (RAAN) | 3.8 V @ 0.67 A/phase, 200 steps/rev
1 | NFP-GW12T-10BY Stepper (MA) | 5 V @ 0.13 A/phase, 1:118 gearbox
1 | Combined OLED + Encoder Module | 1.3″, 128×64, 65×35 mm; 4×M3 @ 60×30 mm
1 | DS3231 RTC Module + CR2032 Holder | I²C RTC (0x68). Avoid charging CR2032; use non-charging variant.
1 | 5.5 mm Barrel Jack | Center-pos, 5 V DC input
2 | 47 µF Electrolytic Capacitors | Bulk decoupling for DRV8834 VMOT
6–8 | 0.1 µF Ceramic Capacitors | Local decoupling (MCU/I²C/encoder/RTC)

## Electrical Summary

Power: Single 5 V input (center-positive) powers Pico 2 and both DRV8834 drivers.
Logic bus: I²C0 at 3.3 V shared by OLED (0x3C) and DS3231 (0x68).
Pull-ups: Provide a single set of SDA/SCL pull-ups to 3.3 V (≈4.7 kΩ). Remove/omit any 5 V pull-ups on add-on modules.
Total current: ≈0.7 A average (low duty), 1–2 A supply recommended for margin.
Cooling: Not required due to low duty cycle.

## Stepper Driver Configuration (DRV8834)

Axis | Motor | I_phase (A) | VREF (V) | Notes
RAAN | SY28STH32-067A | 0.67 | 0.335 | Full-size stepper, 200 steps/rev
Mean AnomalyNFP-GW12T-10BY | | 0.13 | 0.065 | Worm-gear stepper, 1:118

## OLED + Encoder Module

Combined 1.3″ OLED (SSD1106, 128×64) + rotary encoder board with a single 9-pin interface. Module size: 65×35 mm; mounting holes: 60×30 mm rectangle (M3).
Supply: 3.3–5 V confirmed; I²C address 0x3C.
Pin | Signal | Description | Pico GPIO
1 | Confirm | Encoder push (active LOW) | GP18
2 | OLED_SDA | I²C data | GP4
3 | OLED_SCL | I²C clock | GP5
4 | Encoder_Push | Duplicate of Confirm (if present) | —
5 | Encoder_TRA | Encoder channel A | GP16
6 | Encoder_TRB | Encoder channel B | GP17
7 | BAK | Backup line (leave NC) | —
8 | GND | Ground | —
9 | 3V3-5V | Module power (prefer 3.3 V bus) | —

## Real-Time Clock (RTC) – DS3231

Device: DS3231 (TCXO) I²C RTC, address 0x68.
Supply: 2.3–5.5 V. For 3.3 V I²C bus integrity, power the module from 3.3 V (recommended). Backup: CR2032 cell. Use non-charging module revision (or disable/remove charge path) to avoid charging primary cells.
I²C Speed: 100–400 kHz. Shared bus with OLED; standard 100 kHz is fine.
Signals: SDA, SCL to I²C0; optional INT/SQW to an interrupt-capable GPIO for alarms.
Pin | Signal | Description | Pico GPIO
1 | SDA | I²C data (3.3 V) | GP4
2 | SCL | I²C clock (3.3 V) | GP5
3 | VCC | 3.3 V supply (preferred) | 3V3
4 | GND | Ground | GND
5 | INT/SQW | Interrupt/alarm output (optional) | GP21
6 | BAT | CR2032 backup (on module) | —

## Pico 2 Pin Assignments

Axis | Signal | GPIO
RAAN | STEP | GP14
RAAN | DIR | GP15
RAAN | nENBL | GP13
RAAN | nSLEEP | GP12

RAAN | M0 | GP6
RAAN | M1 | GP7
Mean Anomaly | STEP | GP10
Mean Anomaly | DIR | GP11
Mean Anomaly | nENBL | GP9
Mean Anomaly | nSLEEP | GP8
Mean Anomaly | M0 | GP19
Mean Anomaly | M1 | GP20
OLED + Encoder | I²C SDA | GP4
OLED + Encoder | I²C SCL | GP5
OLED + Encoder | Encoder A | GP16
OLED + Encoder | Encoder B | GP17
OLED + Encoder | Confirm Button | GP18
RTC | INT/SQW (optional) | GP21

I²C Bus Notes: Ensure only one set of SDA/SCL pull-ups to 3.3 V (≈4.7 kΩ total). If any module has pull-ups to 5 V, remove or rewire to 3.3 V to protect Pico GPIOs. Some DS3231 boards include a charging circuit for LIR2032 cells; do not charge CR2032 cells.

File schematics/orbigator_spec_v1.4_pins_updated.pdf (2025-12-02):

# Orbigator Control Board – Electronics Specification (v1.4, Pinouts Updated)

This document updates the Orbigator v1.4 specification with the latest Raspberry Pi Pico 2 pin assignments for two ULN2003 stepper drivers, two Pololu-style STEP/DIR drivers, the OLED+RTC I²C bus, and the rotary encoder.

## I²C Bus and User Interface

I²C0 Bus:
Signal | Function | Pico 2 GPIO
I2C0_SDA | OLED + RTC data | GP4
I2C0_SCL | OLED + RTC clock | GP5

Rotary Encoder:
Signal | Function | Pico 2 GPIO
ENC_A | Rotary encoder A | GP16
ENC_B | Rotary encoder B | GP17
ENC_PUSH | Encoder push button (active LOW) | GP18

## ULN2003 Stepper Drivers (28BYJ-48 Motors)

ULN2003 #1 – AOV (Argument-of-Vehicle) 28BYJ-48:
Net | Function | Pico 2 GPIO
AOV_IN1 | ULN2003 #1 IN1 (coil 1) | GP8
AOV_IN2 | ULN2003 #1 IN2 (coil 2) | GP9
AOV_IN3 | ULN2003 #1 IN3 (coil 3) | GP10
AOV_IN4 | ULN2003 #1 IN4 (coil 4) | GP11

ULN2003 #2 – Spare 28BYJ-48 (optional):
Net | Function | Pico 2 GPIO
ULN2_IN1 | ULN2003 #2 IN1 (coil 1) | GP19
ULN2_IN2 | ULN2003 #2 IN2 (coil 2) | GP20
ULN2_IN3 | ULN2003 #2 IN3 (coil 3) | GP21
ULN2_IN4 | ULN2003 #2 IN4 (coil 4) | GP22

## Pololu-Style STEP/DIR Drivers (Bipolar Steppers)

Pololu Driver #1 – LAN Stepper:
Net | Function | Pico 2 GPIO
LAN_STEP | Pololu #1 STEP (LAN / globe rotation) | GP14
LAN_DIR | Pololu #1 DIR | GP15
LAN_M0 | Pololu #1 microstep pin M0 | GP2
LAN_M1 | Pololu #1 microstep pin M1 | GP3
POLOLU_EN | Shared EN/SLEEP for all Pololu drivers | GP13

Pololu Driver #2 – Spare Bipolar Stepper:
Net | Function | Pico 2 GPIO
M2_STEP | Pololu #2 STEP (spare bipolar) | GP0
M2_DIR | Pololu #2 DIR | GP1
M2_M0 | Pololu #2 microstep pin M0 | GP6
M2_M1 | Pololu #2 microstep pin M1 | GP7
POLOLU_EN | Shared EN/SLEEP for all Pololu drivers | GP13

## High-Level Block Diagram

Pico 2 GPIO assignments overview: +------------------------------+ | Pico 2 | | | | I2C0_SDA (GP4) ---- OLED
+ RTC (DS3231) | | I2C0_SCL (GP5) | | | | ENC_A (GP16) ---- Encoder A | | ENC_B (GP17) ----
Encoder B | | ENC_PUSH (GP18) ---- Encoder Switch | | | | AOV_IN1-4 (GP8-11) ---- ULN2003 #1 AOV
| | ULN2_IN1-4 (GP19-22) ---- ULN2003 #2 | | | | LAN_STEP (GP14) ---- Pololu #1 STEP | | LAN_DIR
(GP15) ---- Pololu #1 DIR | | LAN_M0/M1 (GP2,GP3) ---- Pololu #1 M0/M1| | M2_STEP (GP0) ----
Pololu #2 STEP | | M2_DIR (GP1) ---- Pololu #2 DIR | | M2_M0/M1 (GP6,GP7) ---- Pololu #2 M0/M1| |
POLOLU_EN (GP13) ---- EN/SLEEP (shared) | +------------------------------+

## Notes

- EN/SLEEP for all Pololu drivers is shared on GP13 to simplify control. - OLED and DS3231 RTC share the same I²C0 bus on GP4/GP5. - The rotary encoder (A/B/SW) uses GP16/17/18 as verified on the breadboard prototype. - ULN2003 #1 is reserved for the AOV (Argument-of-Vehicle) 28BYJ-48 stepper. - ULN2003 #2 and Pololu #2 are available for future expansion.

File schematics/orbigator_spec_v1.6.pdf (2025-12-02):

# Orbigator Electronics Specification (v1.6)

This version (v1.6) updates the Orbigator electronics specification with the finalized pin map, confirmed electrical behavior of CONFIRM and BACK buttons (active LOW), and revised UI input tables.

## I²C Bus and User Interface

I²C0 Bus:
Signal | Function | Pico GPIO
I2C0_SDA | OLED + DS3231 RTC data | GP4
I2C0_SCL | OLED + DS3231 RTC clock | GP5

OLED + Rotary Encoder Board Inputs:
Module Pin | Signal | Function | Pico GPIO | Electrical
1 | CONFIRM | OK / Select button | GP26 | Active LOW (PULL_UP)
4 | PSH | Encoder push button | GP18 | Active LOW (PULL_UP)
5 | TRA | Encoder A phase | GP16 | Digital input
6 | TRB | Encoder B phase | GP17 | Digital input
7 | BACK | Back / Cancel button | GP27 | Active LOW (PULL_UP)

## ULN2003 Stepper Drivers (28BYJ-48 Motors)

ULN2003 #1 – AOV Stepper:
Net | Function | Pico GPIO
AOV_IN1 | ULN2003 #1 coil 1 | GP8
AOV_IN2 | ULN2003 #1 coil 2 | GP9
AOV_IN3 | ULN2003 #1 coil 3 | GP10
AOV_IN4 | ULN2003 #1 coil 4 | GP11

ULN2003 #2 – Spare Stepper:
Net | Function | Pico GPIO
ULN2_IN1 | ULN2003 #2 coil 1 | GP19
ULN2_IN2 | ULN2003 #2 coil 2 | GP20
ULN2_IN3 | ULN2003 #2 coil 3 | GP21
ULN2_IN4 | ULN2003 #2 coil 4 | GP22

## Pololu-Style STEP/DIR Drivers (Bipolar Steppers)

Pololu #1 – LAN Stepper:
Net | Function | Pico GPIO
LAN_STEP | Pololu #1 STEP | GP14
LAN_DIR | Pololu #1 DIR | GP15
LAN_M0 | Microstep M0 | GP2
LAN_M1 | Microstep M1 | GP3
POLOLU_EN | Shared EN/SLEEP | GP13

Pololu #2 – Spare Bipolar Stepper:
Net | Function | Pico GPIO
M2_STEP | Pololu #2 STEP | GP0
M2_DIR | Pololu #2 DIR | GP1
M2_M0 | Microstep M0 | GP6
M2_M1 | Microstep M1 | GP7
POLOLU_EN | Shared EN/SLEEP | GP13

## High-Level Block Diagram (Table Style)

Pico Pin | Signal Name | Peripheral
GP4 | SDA | OLED + RTC (I²C bus)
GP5 | SCL | OLED + RTC (I²C bus)
GP16 | ENC_A | Rotary Encoder A
GP17 | ENC_B | Rotary Encoder B
GP18 | ENC_PUSH | Encoder Switch
GP26 | CONFIRM | Confirm Button
GP27 | BACK | Back/Cancel Button
GP8–11 | AOV_IN1–4 | ULN2003 #1 (AOV stepper)
GP19–22 | ULN2_IN1–4 | ULN2003 #2 (Spare stepper)
GP14 | LAN_STEP | Pololu #1 STEP
GP15 | LAN_DIR | Pololu #1 DIR
GP2, GP3 | LAN_M0, LAN_M1 | Pololu #1 microstep pins
GP0, GP1 | M2_STEP, M2_DIR | Pololu #2 STEP/DIR
GP6, GP7 | M2_M0, M2_M1 | Pololu #2 microstep pins
GP13 | POLOLU_EN | Shared EN/SLEEP for all Pololu drivers

## Notes

- CONFIRM and BACK buttons verified via multimeter to be active LOW (short to ground when pressed).
- Use internal pull-up resistors for all active-LOW buttons (CONFIRM, BACK, PSH).
- OLED and DS3231 share the I²C0 bus on GP4/GP5.
- ULN2003 #1 drives the AOV motor; ULN2003 #2 is available for expansion.
- Pololu #1 drives the LAN stepper; Pololu #2 is available for future expansion.
- EN/SLEEP line is shared across both Pololu drivers.

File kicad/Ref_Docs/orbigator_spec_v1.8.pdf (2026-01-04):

# Orbigator Electronics Specification

## Version 1.8

This document consolidates all electrical, mechanical, and interface specifications for the Orbigator project, including complete Pico 2 pin mapping, UI input definitions, motor driver interfaces, power notes, and a full hyperlinked Bill of Materials (BOM).

# 1. System Overview

The Orbigator is a dual■axis orbit visualization mechanism. It uses: - A LAN rotational axis (Pololu■driven bipolar stepper) - An Argument■of■Vehicle (AOV) stepper axis (ULN2003 + 28BYJ■48) - A user interface module integrating an OLED display, rotary encoder, encoder push, and CONFIRM/BACK buttons - A DS3231 real■time clock sharing the same I²C bus All electronics are controlled by a Raspberry Pi Pico 2.

## High■Level Functional Block Diagram

Pico Pin | Signal | Subsystem
GP4 | SDA | OLED + DS3231 (I2C)
GP5 | SCL | OLED + DS3231 (I2C)
GP16 | ENC_A | Rotary Encoder A
GP17 | ENC_B | Rotary Encoder B
GP18 | ENC_PUSH | Encoder Push (active LOW)
GP26 | CONFIRM | UI Button (active LOW)
GP27 | BACK | UI Button (active LOW)
GP8■11 | AOV_IN1■4 | ULN2003 #1 (AOV Stepper)
GP19■22 | ULN2_IN1■4 | ULN2003 #2 (Spare Stepper)
GP14 | LAN_STEP | Pololu #1 STEP
GP15 | LAN_DIR | Pololu #1 DIR
GP2,3 | LAN_M0,M1 | Pololu #1 Microstep Pins
GP0,1 | M2_STEP,DIR | Pololu #2 STEP/DIR
GP6,7 | M2_M0,M1 | Pololu #2 Microstep Pins
GP13 | POLOLU_EN | Shared EN/SLEEP

# 2. Pico 2 Pin Map

The following tables define all GPIO assignments for firmware and PCB layout. These match pins.py.

## 2.1 I²C + User Interface

Signal | Function | GPIO | Electrical
SDA | OLED + RTC data | GP4 | I²C
SCL | OLED + RTC clock | GP5 | I²C
ENC_A | Encoder A | GP16 | Digital
ENC_B | Encoder B | GP17 | Digital
ENC_PUSH | Encoder push | GP18 | Active LOW (pull■up)
CONFIRM | Confirm button | GP26 | Active LOW (pull■up)
BACK | Back button | GP27 | Active LOW (pull■up)

## 2.2 ULN2003 Stepper Driver Pins

Motor | Signal | GPIO | Notes
AOV Stepper | AOV_IN1 | GP8
| AOV_IN2 | GP9
| AOV_IN3 | GP10
| AOV_IN4 | GP11
Spare | ULN2_IN1 | GP19
| ULN2_IN2 | GP20
| ULN2_IN3 | GP21
| ULN2_IN4 | GP22

## 2.3 Pololu DRV8834 Stepper Driver Pins

Driver | Signal | GPIO | Notes
Pololu #1 (LAN) | STEP | GP14
| DIR | GP15
| M0 | GP2
| M1 | GP3
Pololu #2 (Spare) | STEP | GP0
| DIR | GP1
| M0 | GP6

| M1 | GP7
Shared | EN/SLEEP | GP13 | Shared across both drivers

# 3. OLED + Encoder Module

The user interface module includes an OLED, rotary encoder, encoder push button, and dedicated CONFIRM and BACK buttons.

Pin # | Signal | Function
1 | CONFIRM | Confirm button (active LOW)
2 | SDA | OLED I²C data
3 | SCL | OLED I²C clock
4 | PSH | Encoder push (active LOW)
5 | TRA | Encoder A
6 | TRB | Encoder B
7 | BAK | Back button (active LOW)
8 | GND | Ground
9 | VCC | 3.3–5V input

# 4. Real■Time Clock (DS3231)

The DS3231 module shares the I²C0 bus with the OLED. It uses SDA/SCL on GP4/GP5. Module includes onboard pull■ups; external pull■ups not required.

# 5. Bill of Materials (BOM)

Item | Component | Notes / Footprint | Link
1 | Raspberry Pi Pico 2 | 2×20 DIP | https://www.raspberrypi.com/products/raspberry-pi-pico-2/
2 | ULN2003 Boards (x2) | IN1■IN4 headers | https://www.pololu.com/product/2130
3 | DRV8834 Pololu Drivers (x2) | A4988 footprint | https://www.pololu.com/product/2134
4 | OLED + Encoder Module | 9■pin header + mounts | https://www.crcibernetica.com/i2c-oled-display-with-ec11-rotary-encoder/
5 | DS3231 RTC | 4■pin header | https://www.adafruit.com/product/3013
6 | 28BYJ■48 Stepper | AOV axis | https://www.sparkfun.com/products/10551
7 | NFP■GW12T■10BY Motor | LAN axis | https://www.nfp-motor.com/gw12-by-series
8 | DC Barrel Jack | 5.5×2.1mm | https://www.sparkfun.com/products/119
9 | Pin Headers | 2.54mm | https://www.sparkfun.com/products/116

# 6. Notes for PCB Design

- CONFIRM, BACK, and encoder push are active■LOW; use internal pull■ups. - OLED/Encoder module mounting: 60mm × 30mm, M3 holes. - Shared EN/SLEEP line on GP13 drives both Pololu drivers. - I²C bus shared cleanly by OLED and DS3231. - Pololu modules must use the standard A4988 footprint. - ULN2003 modules vary; recommended: bring signals to headers.

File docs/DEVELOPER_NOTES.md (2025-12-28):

# Orbigator Developer Notes

## Serial Port Management (Thonny vs mpremote)

### Clearing the Serial Port
If `mpremote` locks the serial port (`/dev/ttyACM0`) or if Thonny cannot connect due to a "Device is busy" error, the following command is the most effective way to force-clear the connection:

```bash
pkill -9 -f mpremote
```

Run this command in the terminal to immediately kill any background `mpremote` processes and free up the USB resource. This is safe to use between deployment scripts and Thonny sessions.

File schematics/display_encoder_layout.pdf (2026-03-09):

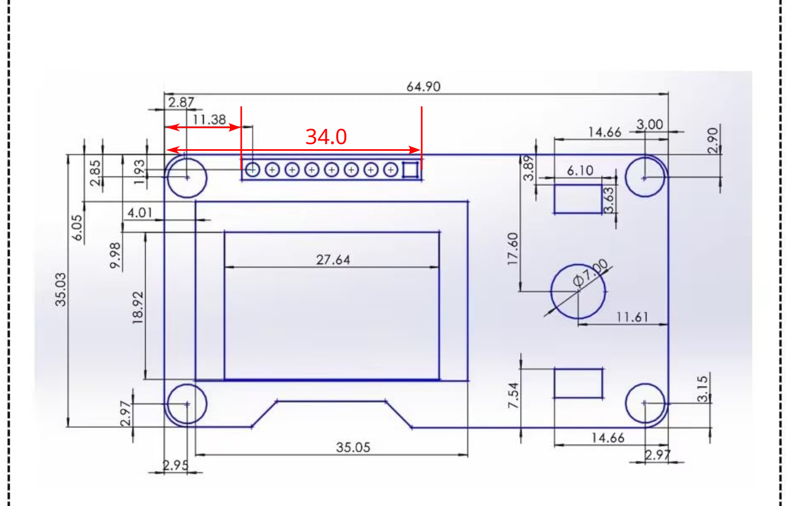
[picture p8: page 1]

34.0

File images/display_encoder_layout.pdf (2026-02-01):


34.0

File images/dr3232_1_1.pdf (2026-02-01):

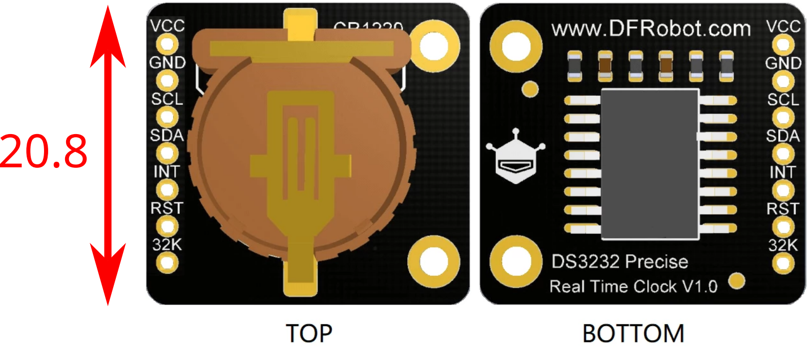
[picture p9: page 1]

20.8

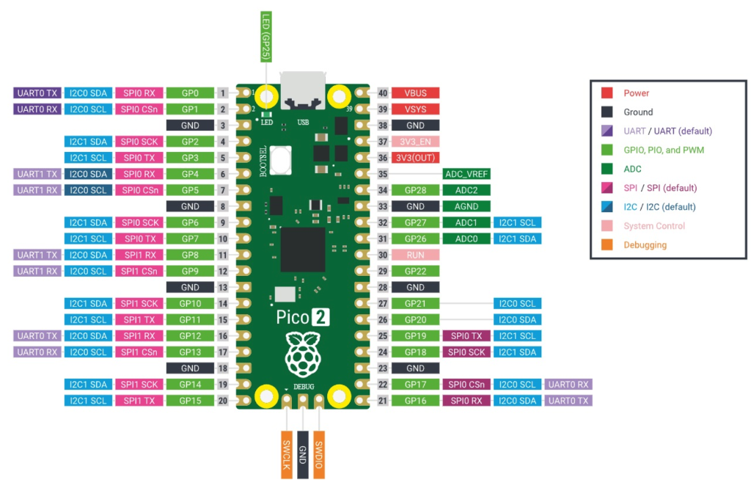
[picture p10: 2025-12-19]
images/pico2_pinout.png

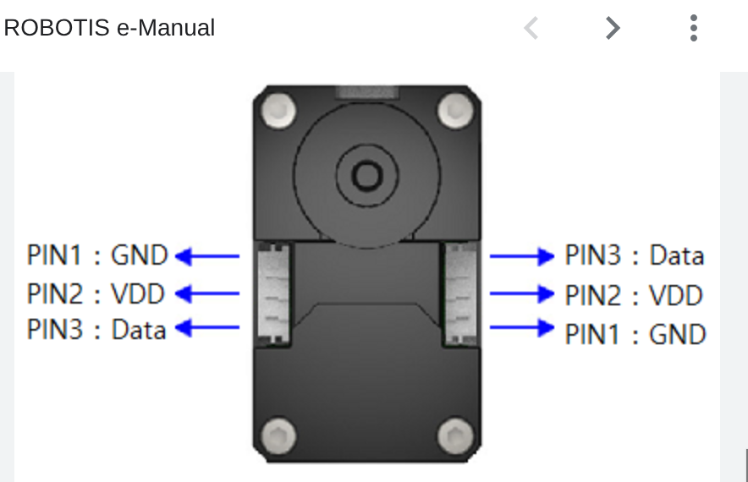
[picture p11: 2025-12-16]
images/dynamixel_official_pinout.png

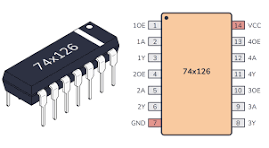
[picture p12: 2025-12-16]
images/74x126_pinout.png

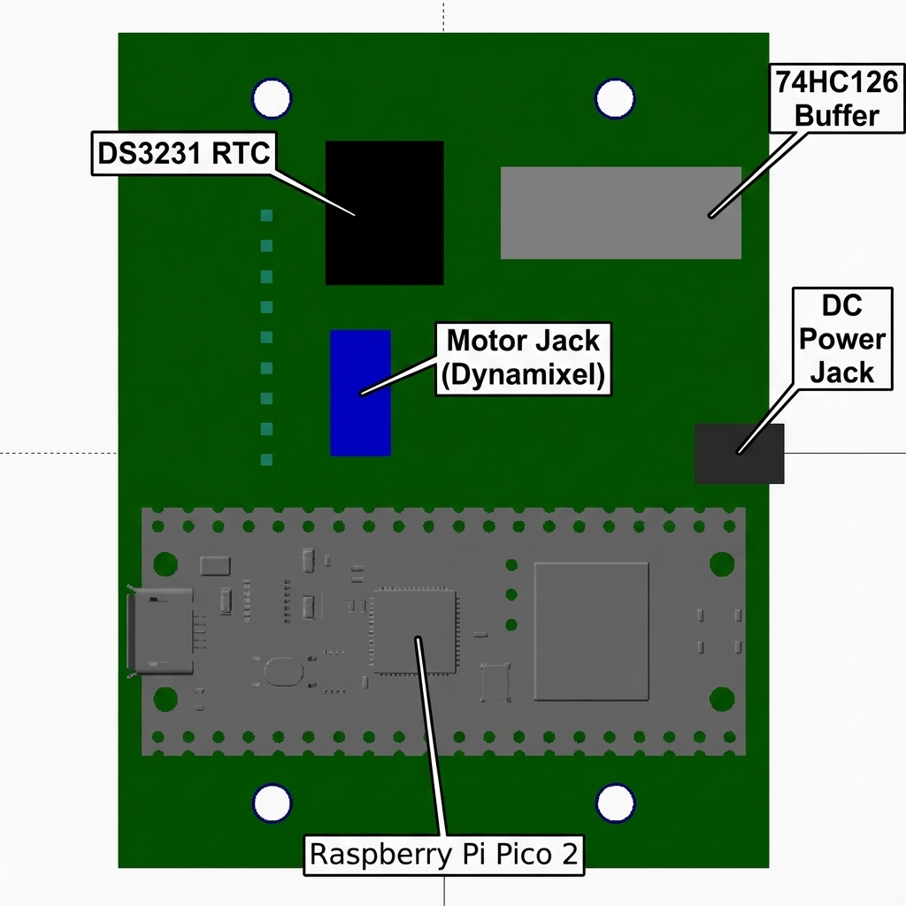
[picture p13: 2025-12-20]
schematics/orbigator_pcb_layout_labeled.png

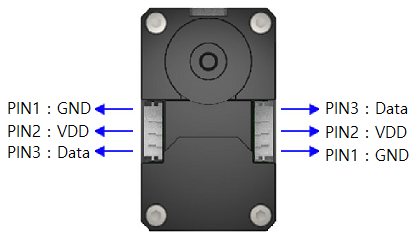
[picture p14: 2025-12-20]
schematics/dynamixel_xl330_pinout.png

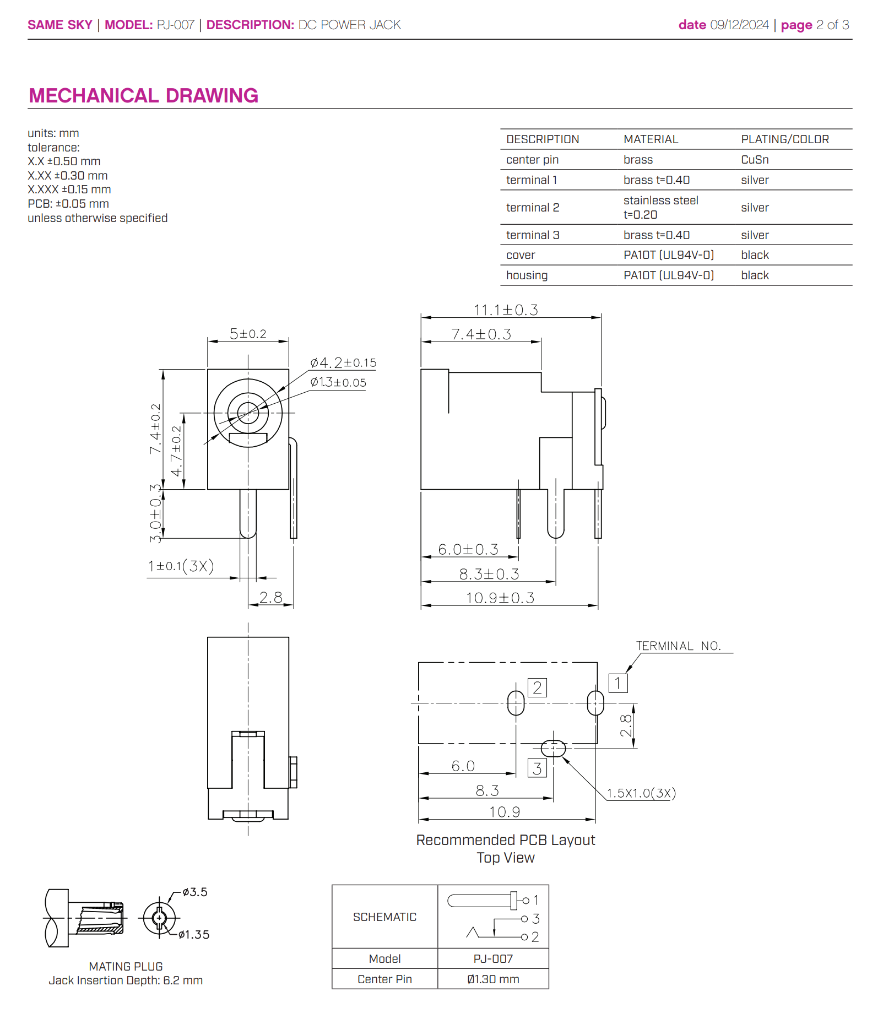
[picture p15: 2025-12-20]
schematics/dc_power_jack_pj007_drawing.png

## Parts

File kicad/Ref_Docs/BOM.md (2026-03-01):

# Orbigator Bill of Materials (BOM)

## Microcontroller

| Ref | Qty | Value | Description | Footprint | Datasheet | Notes |
|-----|-----|---|---|---|---|---|
| U1 | 1 | Raspberry Pi Pico 2 | RP2350 Microcontroller Board | Module:Raspberry_Pi_Pico_SMD | [Link](https://datasheets.raspberrypi.com/pico/pico-2-datasheet.pdf) | Main controller |

## Logic ICs

| Ref | Qty | Value | Description | Footprint | Datasheet | Notes |
|-----|-----|---|---|---|---|---|
| U2 | 1 | 74HC126 | Quad Tri-State Buffer | Package_DIP:DIP-14_W7.62mm | [Link](https://www.ti.com/lit/ds/symlink/sn74hc126.pdf) | UART direction control |

## Display & RTC

| Ref | Qty | Value | Description | Footprint | Datasheet | Notes |
|-----|-----|---|---|---|---|---|
| DISP1 | 1 | SSD1306/SH1106 | 128x64 OLED Display | Display:OLED_128x64_I2C | [Link](https://cdn-shop.adafruit.com/datasheets/SSD1306.pdf) | I2C Address: 0x3C |
| RTC1 | 1 | DS3232 | Real-Time Clock Breakout | Module:Fermion_DS3232 | [Link](https://www.dfrobot.com/product-2241.html) | I2C Address: 0x68 (High Precision) |

## Motors

| Ref | Qty | Value | Description | Footprint | Datasheet | Notes |
|-----|-----|---|---|---|---|---|
| M1 | 1 | XL330-M288-T | DYNAMIXEL Servo (ID 1) | Connector_JST:JST_EH_B3B-EH-A_1x03_P2.50mm_Vertical | [Link](https://emanual.robotis.com/docs/en/dxl/x/xl330-m288/) | EQX Motor, 11T→120T gearing |
| M2 | 1 | XL330-M288-T | DYNAMIXEL Servo (ID 2) | Connector_JST:JST_EH_B3B-EH-A_1x03_P2.50mm_Vertical | [Link](https://emanual.robotis.com/docs/en/dxl/x/xl330-m288/) | AoV Motor, direct drive |

## User Interface

| Ref | Qty | Value | Description | Footprint | Datasheet | Notes |
|-----|-----|---|---|---|---|---|
| ENC1 | 1 | Rotary Encoder | Encoder with push button | Rotary_Encoder:RotaryEncoder_Alps_EC11E-Switch_Vertical_H20mm | - | User input |

## Resistors

| Ref | Qty | Value | Description | Footprint | Datasheet | Notes |
|-----|-----|---|---|---|---|---|
| R1 | 1 | 10kΩ | Pull-up resistor | Resistor_THT:R_Axial_DIN0207_L6.3mm_D2.5mm_P10.16mm_Horizontal | - | DYNAMIXEL DATA bus pull-up to +5V |
| R2 | 1 | 4.7kΩ | Pull-up resistor | Resistor_THT:R_Axial_DIN0207_L6.3mm_D2.5mm_P10.16mm_Horizontal | - | I2C SDA pull-up to +3.3V **CRITICAL** |
| R3 | 1 | 4.7kΩ | Pull-up resistor | Resistor_THT:R_Axial_DIN0207_L6.3mm_D2.5mm_P10.16mm_Horizontal | - | I2C SCL pull-up to +3.3V **CRITICAL** |

## Connectors

| Ref | Qty | Value | Description | Footprint | Datasheet | Notes |
|-----|-----|---|---|---|---|---|
| J1 | 1 | Barrel Jack | 5V Power Input | Connector_BarrelJack:BarrelJack_Horizontal | - | 5V 4-5A supply |
| J2 | 1 | JST-EH 3-pin | DYNAMIXEL Bus | Connector_JST:JST_EH_B3B-EH-A_1x03_P2.50mm_Vertical | - | Motor daisy-chain |
| J3 | 1 | Header 5-pin | Rotary Encoder | Connector_PinHeader_2.54mm:PinHeader_1x05_P2.54mm_Vertical | - | A, B, SW, VCC, GND |

## Optional Components

| Ref | Qty | Value | Description | Footprint | Datasheet | Notes |
|-----|-----|---|---|---|---|---|
| BAT1 | 1 | CR2032 | Coin cell battery | Battery:BatteryHolder_Keystone_3000_1x12mm | - | Alternative to supercap (larger footprint) |

## Assembly Notes

### Critical Requirements

1. **I2C Pull-ups (R2, R3)**: 
   - **MUST** be installed for reliable I2C communication
   - Without these, OLED will glitch and RTC will be unreliable
   - Individual module pull-ups are NOT sufficient

2. **RTC Backup Power**:
   - Use a **CR2032** battery (BAT1) for 5-10 years backup.
   - Connect to the `V_BAT` pin on the DS3232 module.

3. **DYNAMIXEL Pull-up (R1)**:
   - Required for reliable half-duplex communication
   - Must be connected to +5V (motor supply voltage)

### Power Distribution

- **3.3V Rail** (from Pico): U2, DISP1, RTC1, ENC1
- **5V Rail** (external): M1, M2, R1 pull-up
- **Common Ground**: All components

### Connector Pinouts

**J2 - DYNAMIXEL (JST-EH 3-pin)**:
1. GND
2. VDD (+5V)
3. DATA

**J3 - Encoder (5-pin header)**:
1. A (GP6)
2. B (GP7)
3. SW (GP8)
4. VCC (+3.3V)
5. GND

## Cost Estimate

| Category | Estimated Cost (USD) |
|---|---|
| Pico 2 | $5.00 |
| Motors (2x) | $50.00 |
| Display | $8.00 |
| RTC Module | $10.00 |
| Encoder | $2.00 |
| Passives & ICs | $5.00 |
| PCB (prototype) | $10.00 |
| **Total** | **~$90.00** |

## Sourcing

- **Pico 2**: Adafruit, Pimoroni, SparkFun
- **DYNAMIXEL XL330-M288-T**: ROBOTIS official store
- **OLED Display**: Adafruit, Amazon, AliExpress
- **DS3232 RTC**: DFRobot Fermion, Amazon
- **Passives**: Digi-Key, Mouser, LCSC

## Revision History

| Version | Date | Author | Changes |
|---|---|---|---|
| 1.0 | 2025-12-21 | Justin Shaw | Initial BOM with supercap backup option |
| 2.0 | 2026-03-01 | Antigravity | Corrected RTC to Fermion DS3232 and removed supercap/capacitors based on V2 reality |

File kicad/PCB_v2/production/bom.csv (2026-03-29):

Designator | Footprint | Quantity | Value | LCSC Part # | JLCPCB Part # | LINK
BT1 | batt+AF8-HARWIN+AF8-S8201+AC0-46R | 1 | CR1220 | C6214863 |  | https://www.lcsc.com/product+AC0-detail/C6214863.html | DNP
C1, C2, C3, C5, C6, C7, C9 | 805 | 7 | 100nF | C49678 |  | https://www.lcsc.com/product+AC0-detail/C49678.html
C8 | SMD,D6.3xL5.8mm | 1 | 100uF | C178540 |  | https://www.lcsc.com/product+AC0-detail/C178540.html
D1 | D+AF8-SMA | 1 | B130 | C134423 |  | https://www.lcsc.com/product+AC0-detail/C134423.html
DISP1 | OLED+AF8-ENC3 | 1 | OLED+AF8-Encoder | C2897372 |  | https://www.lcsc.com/product+AC0-detail/C2897372.html
J27 | BarrelJack+AF8-Horizontal | 1 | Barrel+AF8-Jack+AF8-Switch | C381116 |  | https://www.lcsc.com/product+AC0-detail/C381116.html
M1 | JST+AF8-EH+AF8-B3B+AC0-EH+AC0-A+AF8-1x03+AF8-P2.50mm+AF8-Vertical | 1 | DYNAMIXEL+AF8-1 | C160259 |  | https://www.lcsc.com/product+AC0-detail/C160259.html
M2 | JST+AF8-EH+AF8-B3B+AC0-EH+AC0-A+AF8-1x03+AF8-P2.50mm+AF8-Vertical | 1 | DYNAMIXEL+AF8-2 | C160259 |  | https://www.lcsc.com/product+AC0-detail/C160259.html
Q1 | SOT+AC0-23 | 1 | DMG2305UX | C2940629 |  | https://www.lcsc.com/product-detail/C2940629.html?s_z=n_DMG2305UX
R1, R2, R3, R4, R5 | 805 | 5 | 10k | C84376 |  | https://www.lcsc.com/product+AC0-detail/C84376.html
U1 | RaspberryPi_Pico_SMD_HandSolder | 1 | Pico_2 |  | C41407547 | https://jlcpcb.com/partdetail/RaspberryPi+AC0-Pico2/C41407547 | DNP
U2 | SOIC+AC0-14_3.9x8.7mm_P1.27mm | 1 | 74LS126 | C7644 |  | https://www.lcsc.com/product+AC0-detail/C7644.html
U4 | SOIC+AC0-8_3.9x4.9mm_P1.27mm | 1 | DS3232M | C2827535 |  | https://www.lcsc.com/product+AC0-detail/C2827535.html

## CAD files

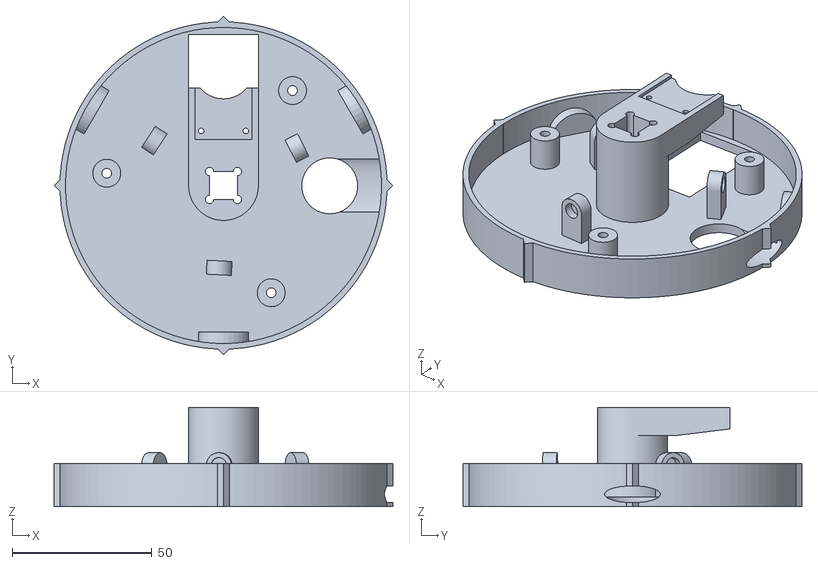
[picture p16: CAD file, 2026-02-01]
fabricate/stls/test_assembly.stl
121.5 x 121.5 x 35.5

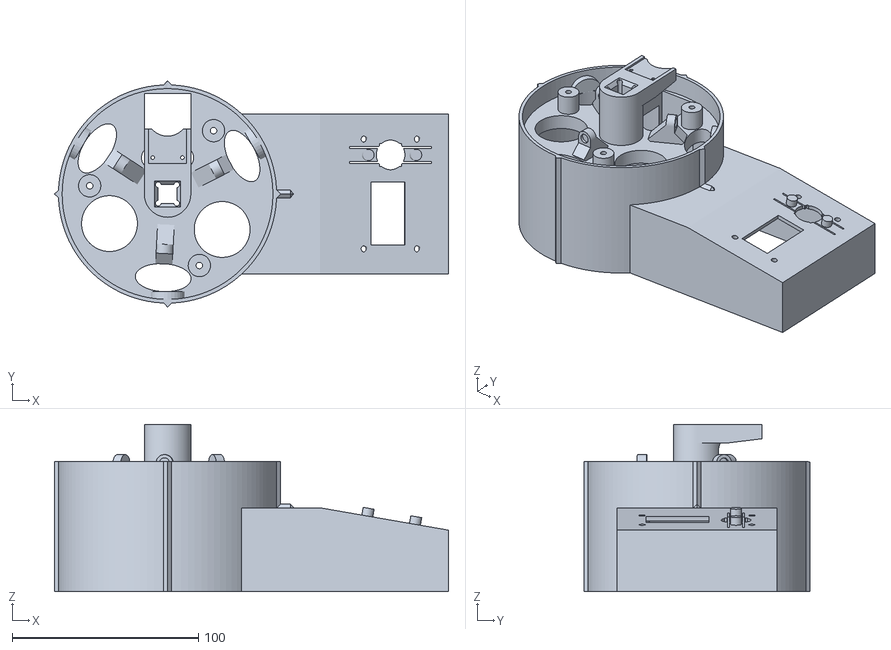
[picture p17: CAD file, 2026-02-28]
fabricate/stls/Production/1_full_assembly.stl
211.8 x 121.5 x 89.8

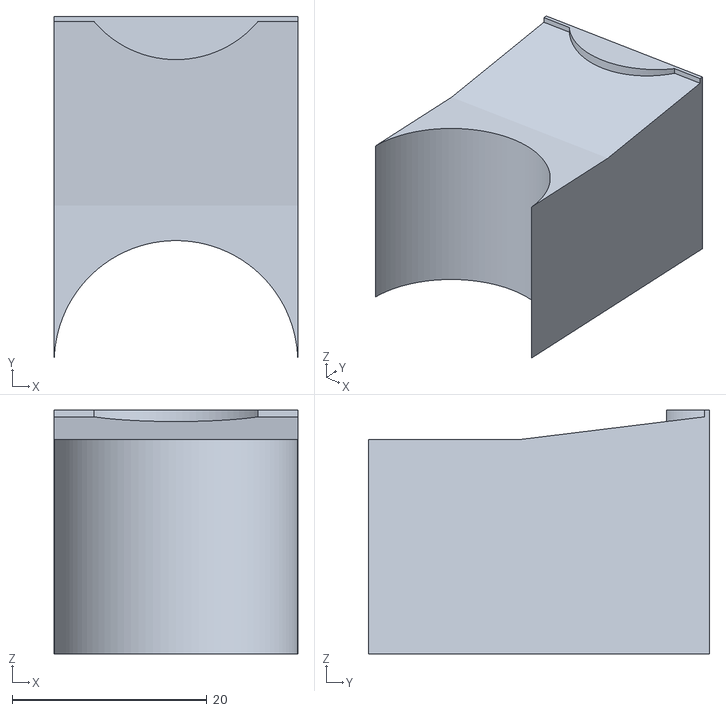
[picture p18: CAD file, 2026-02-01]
fabricate/stls/test_assembly_support.stl
25.0 x 35.0 x 25.0

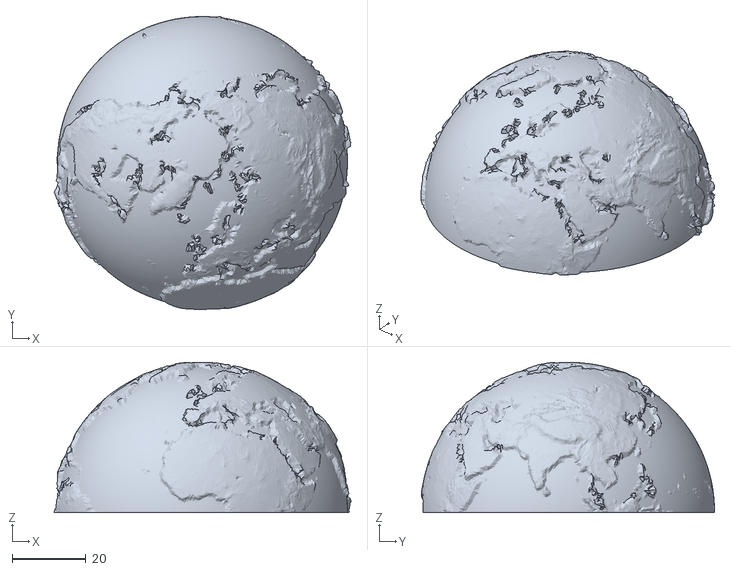
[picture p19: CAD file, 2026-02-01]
data/earth_stls/earthmap_north.stl
80.5 x 79.5 x 40.7

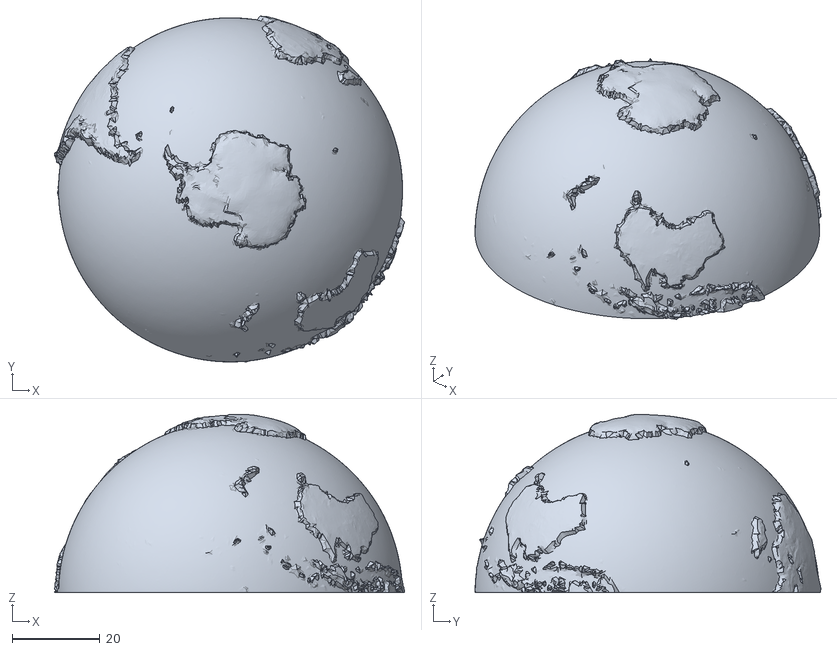
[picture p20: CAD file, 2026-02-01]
fabricate/earthmap_south.stl
80.0 x 79.0 x 40.7

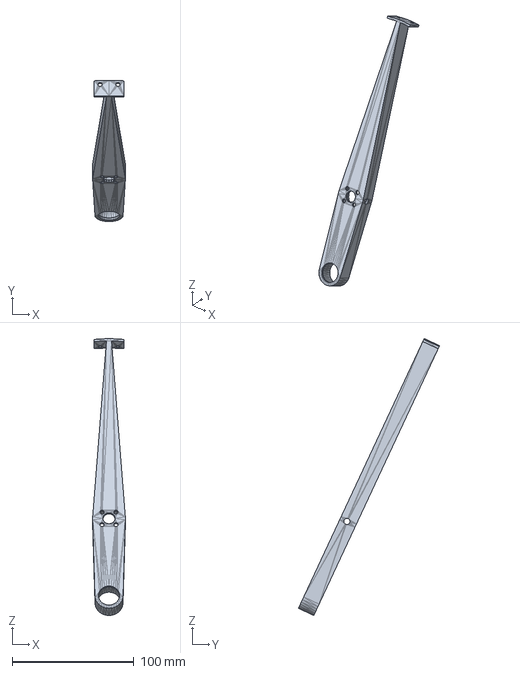
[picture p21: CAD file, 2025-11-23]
fabricate/step_files/aov_arm.step
26.9 x 116.1 x 227.7 mm

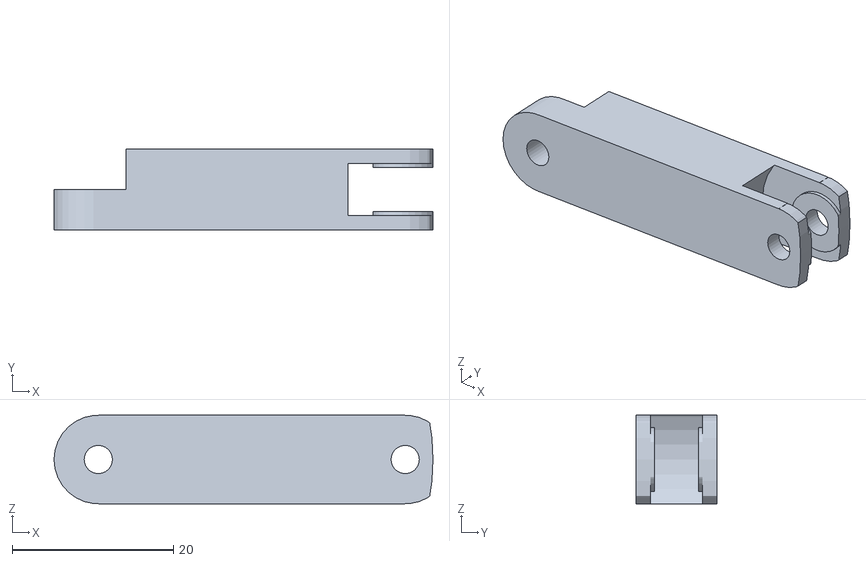
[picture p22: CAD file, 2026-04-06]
fabricate/stls/Production/3_swingarm.stl
47.0 x 10.0 x 11.0

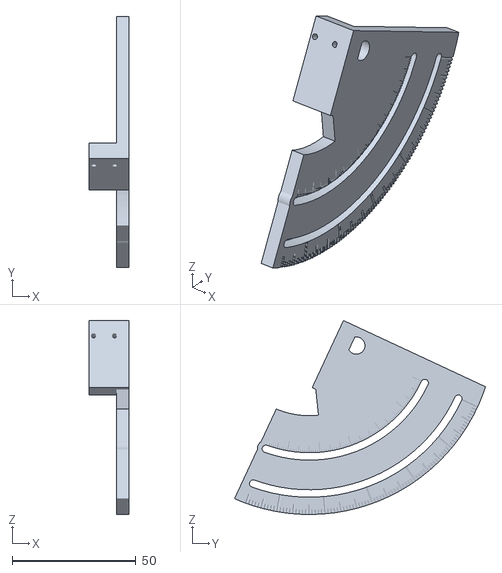
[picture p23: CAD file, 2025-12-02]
fabricate/stls_in_situ/aov_motor_mount.stl
16.0 x 101.6 x 78.5

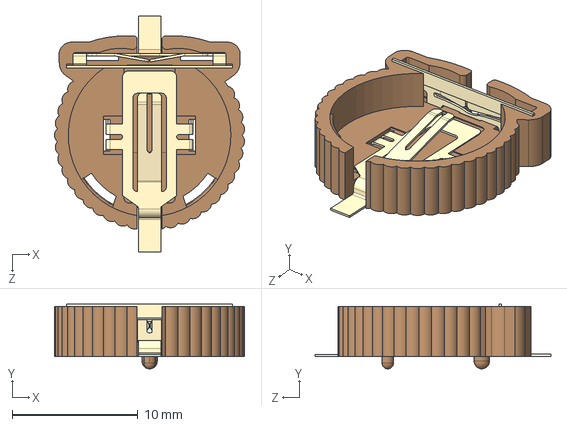
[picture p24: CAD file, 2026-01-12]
kicad/DS3232/1056/1056.step
15.1 x 5.16 x 18.8 mm

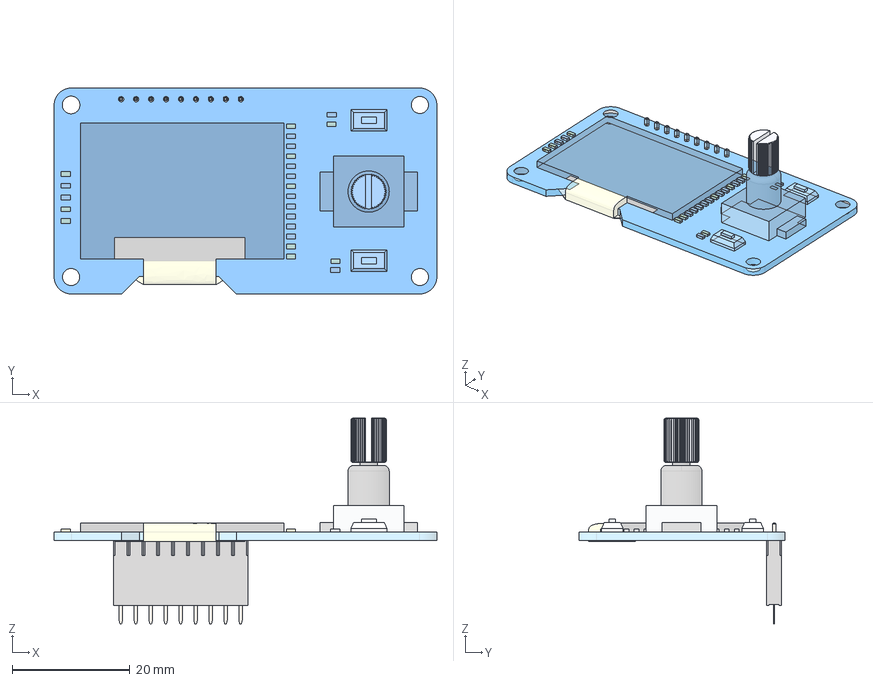
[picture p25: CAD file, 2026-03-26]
kicad/PCB_v2/3D_models/OLED/OLED_Encoder2.step
65.0 x 35.0 x 34.9 mm

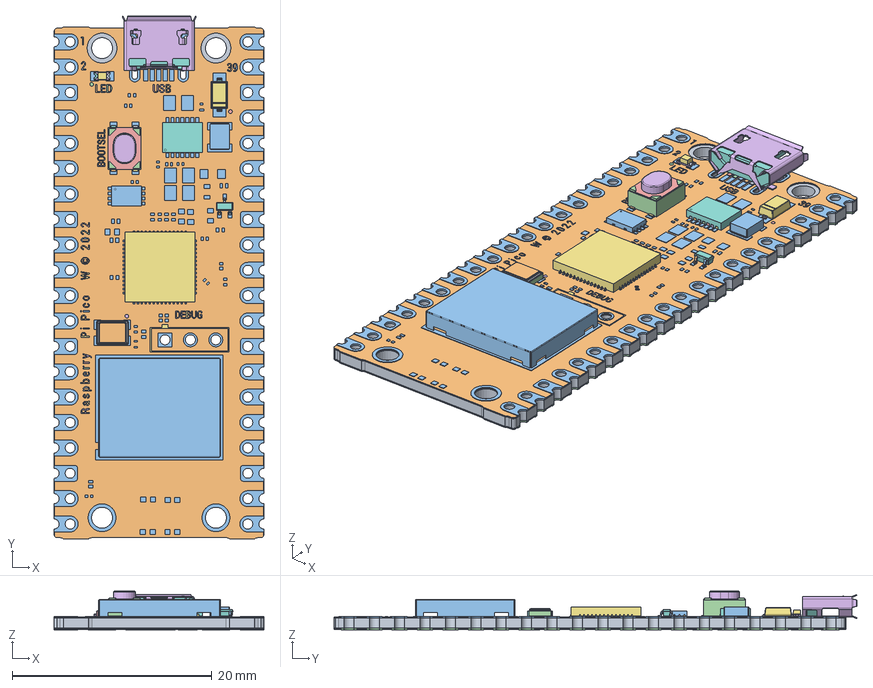
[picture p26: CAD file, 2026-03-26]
kicad/PCB_v2/3D_models/Raspberry_pi_pico-v1.FCStd
21.0 x 52.3 x 3.86 mm
Textolit
Mask_upper
Padstack_upper
Padstack_bottom
Mask_bottom
Raspberry Pi
Raspberry Pi001
Raspberry Pi002
Raspberry Pi003
Raspberry Pi004
Raspberry Pi005
Raspberry Pi006
Raspberry Pi007
Raspberry Pi008
Raspberry Pi009
Raspberry Pi010
Raspberry Pi011
Raspberry Pi012
Raspberry Pi013
Raspberry Pi014
Raspberry Pi015
Raspberry Pi016
Raspberry Pi017
Raspberry Pi018
Raspberry Pi019
Raspberry Pi020
Raspberry Pi021
Raspberry Pi022
Raspberry Pi023
BOOTSEL
BOOTSEL001
BOOTSEL002
BOOTSEL003
BOOTSEL004
BOOTSEL005
BOOTSEL006
DEBUG
DEBUG001
DEBUG002
DEBUG003
DEBUG004
LED
LED001
LED002
USB
USB001
USB002
dig_1
dig_2
dig_39
dig_040
dot_001
dot_002
dot_003
border002
Frame001
Contact006
Contact007
Contact008
Contact009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

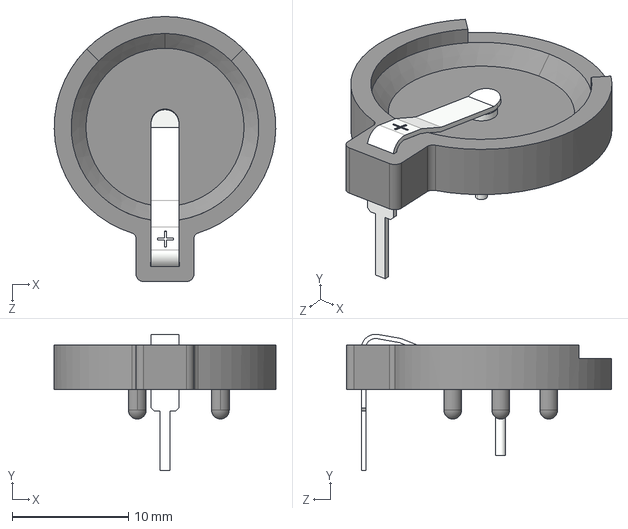
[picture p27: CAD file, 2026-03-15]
kicad/Ref_Docs/kicad_assets/battery_502/502--3DModel-STEP-630548.STEP
19.0 x 11.7 x 22.8 mm

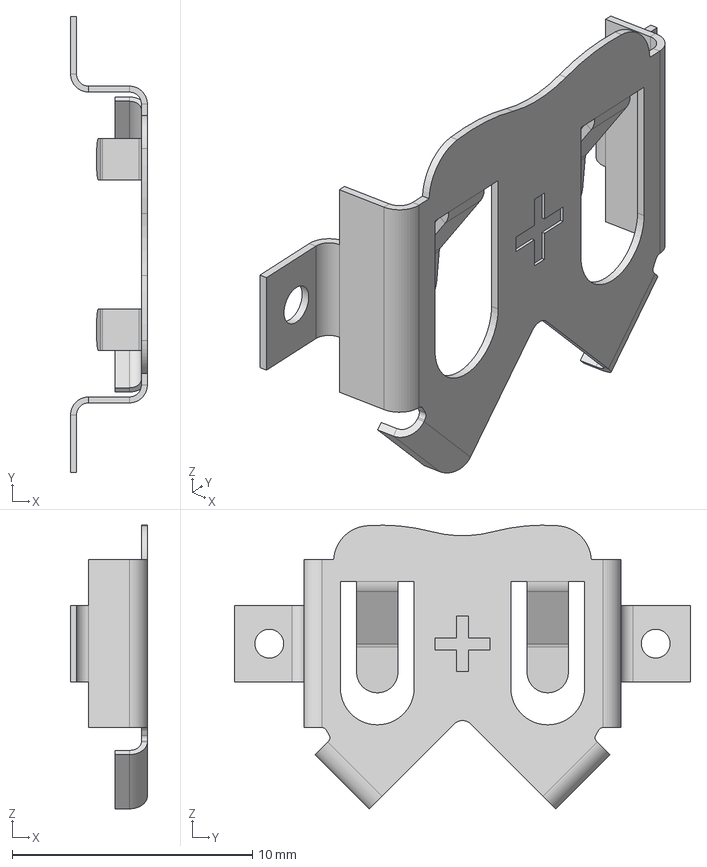
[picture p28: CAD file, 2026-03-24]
kicad/Ref_Docs/kicad_assets/battery_harwin_S8201_46R/S8201-46R.stp
3.20 x 19.0 x 11.8 mm

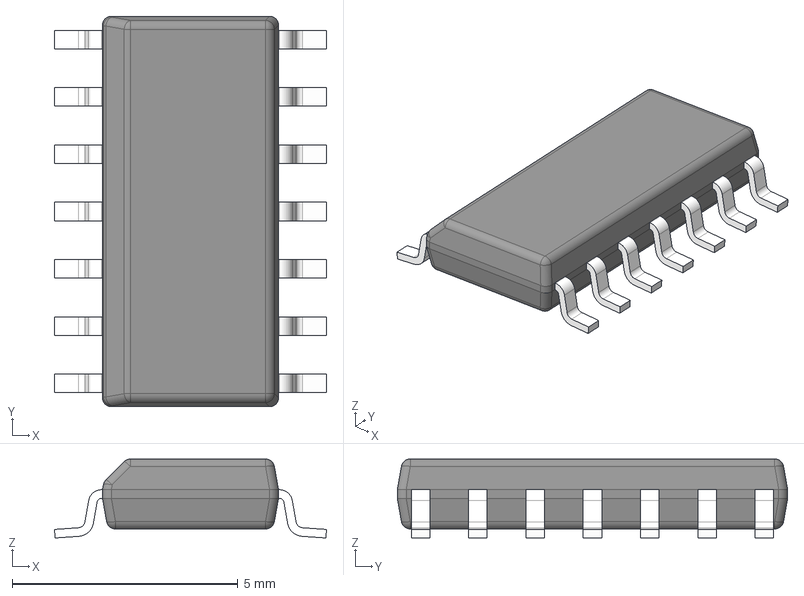
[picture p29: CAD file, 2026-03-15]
kicad/Ref_Docs/kicad_assets/buffer_SN74LS126ADR/D0014A.stp
6.03 x 8.65 x 1.75 mm
BODY-SO
LEAD-SO x 14
PIN1-ID

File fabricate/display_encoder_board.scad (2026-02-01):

board_w = 35;
board_l = 65;
board_h = 2;
hole_offset = 3;
hole_d = 3.5;

screen_w = 23;
screen_l = 35;
screen_h = 1;
screen_offset_l = 5;
screen_offset_w = 6;

knob_d = 14.5;
knob_h = 22;
knob_offset_l = 52.5 - board_l/2+1;
knob_offset_w = 0;

module screen(){
  color("black")
    translate([-board_w/2+screen_offset_l,
	       -board_l/2+screen_offset_w, 0])
    cube([screen_w, screen_l, screen_h]);
}

module screen_hole(){
    translate([-board_w/2+screen_offset_l-1,
	       -board_l/2+screen_offset_w-1, -5])
    cube([screen_w+2, screen_l+2, screen_h+10]);
}
inch = 25.4;
module pins(){
  translate([-board_w/2+.1*inch, -board_l/2 + .474*inch, -6]){
    for(i=[0:8]){
      translate([0, i * .1 * inch, 2])cube([1, 1, 10],center=true);
    }
    //translate([0,-9,0])cylinder(d=3.5, h=10, $fn=30);
  }
}
module knob(){
  translate([knob_offset_w, knob_offset_l, 0])color("darkgrey")cylinder(d=knob_d, h=knob_h);
}

module knob_hole(){
  translate([knob_offset_w, knob_offset_l, -5])rotate([0,0,45])
    cylinder(d=knob_d+4, h=knob_h+10, $fn=40);
}

module display_board(){
  difference(){
    color("darkblue")translate([0,0,-board_h/2])cube([board_w, board_l, board_h], center=true);
    for(i=[-1,1]){
      for(j=[-1,1]){
	translate([i * (board_w/2 - hole_offset), j * (board_l/2 - hole_offset), 0])
	  cylinder(d=hole_d, h=10, center=true, $fn=30);
      }
    }
  }
}

module button(){
  translate([0,0,1])cube([2, 4, 2], center=true);
}
module buttons(){
  translate([knob_offset_w-12, knob_offset_l, 0])color("lightgrey")button();
  translate([knob_offset_w+12, knob_offset_l, 0])color("lightgrey")button();
}

module display_assy(){
  translate([0,0,-2.5]){
    display_board();
    screen();
    knob();
    pins();
    buttons();
  }
}

module display_screws(){
  for(i=[-1,1]){
    for(j=[-1,1]){
      translate([i * (board_w/2 - hole_offset), j * (board_l/2 - hole_offset), 0])
	cylinder(d=hole_d, h=30, center=true, $fn=30);
    }
  }
}

module display_spacer(){
  $fn=30;
  difference(){
    cylinder(d=8, h=2.5);
    translate([0,0,-1])cylinder(d=3.5, h=2.5+2);
  }
}
module display_spacers(){
  translate([0,0,-2.5])
  for(i=[-1,1]){
    for(j=[-1,1]){
      translate([i * (board_w/2 - hole_offset), j * (board_l/2 - hole_offset), 0])display_spacer();
    }
  }
}
//display_spacers();
//buttons();
display_assy();
//translate([0,0,0])screen_hole();

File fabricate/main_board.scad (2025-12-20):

use <display_encoder_board.scad>


main_w = 55;
main_l = 70;
main_h = 3;

module ds3231(){
  color("black")cube([10, 12, 1.5], center=true);
}

inch = 25.4;
module motor_jack(){
  color("blue")cube([.2 * inch, 10.5, 8],center=true);
}

module chip_74hc126(){
    color("darkgrey")cube([.8*inch, .3*inch, 4],center=true);
}

module barrel_jack(){
  translate([0,0,-2])difference(){
    color([.2, .2, .2])cube([11, 5, 7.5], center=true);
    translate([1, 0, 0])rotate([0, 90, 0])cylinder(d=4.2, h=10, $fn=20);
  }
}

module mounting_screws(){
  display_screws();
}

module main_board(){
  difference(){
    color("darkgreen")cube([main_w, main_l, main_h], center=true);
    display_screws();
  }
}

module main_assy(){
  translate([0,0,-5-2.3]){
    translate([-7,-5,-5])motor_jack();
    translate([-5,-20,-2])ds3231();
    translate([15,-20,-3])chip_74hc126();
    translate([25,0,-3])barrel_jack();
    
    translate([0,0,5])display_assy();
    translate([0, 15, -3])rotate([0,180,90])color("grey")import("stls/pi-pico-2w-cad-reference.stl");
    main_board();
  }
}

main_assy();

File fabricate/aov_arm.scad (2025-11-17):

inch = 25.4;

globe_d = 13 * inch;
globe_r = globe_d/2;
globe_thickness = 2;
globe_ir = globe_r - globe_thickness;


height = 14;

RR = 70;
rr = RR - 40;
dd = 8; // magnet support offset from globe_ir

flange_d = 23;
um3_tol = .1;
penny_d = .75 * inch + um3_tol;
penny_t = .06 * inch;

module penny_compartment(dd){
  difference(){
    hull(){
      translate([0,0,0])cylinder(d=flange_d + 4, h=height);
      translate([-dd,0,0])cylinder(d=penny_d + 4, h=height);
    }
    translate([0,0,-2])translate([-dd,0,0])cylinder(d=penny_d, h=height);
    translate([0,0,-2])translate([-dd,0,0])cylinder(d=penny_d * .9, h=height * 2);
  }
  difference(){
    cylinder(d=flange_d + 4, h=.2);
    translate([0,0,-1])cylinder(d=penny_d - .2, h=3);
  }
}

module aov_arm(){
  rotate([0,0,180]){
    difference(){
      union(){
	hull(){
	  cylinder(d=flange_d + 4, h=height);
	  translate([globe_ir-1,-2,0])cube([.1,4,height]);
	}
	penny_compartment(70);
      }
      translate([0,0,-1])cylinder(h=height-1, d=flange_d);
      translate([0,0,-1])cylinder(h=height*2, d=10);
      for(i=[1:4]){
	rotate([0,0,45 + 90 * i])translate([8,0,0])cylinder(d=3.5, h=30, $fn=30);
      }
      translate([0,0,8])rotate([90,0,0])cylinder(d=5, h=40, $fn=30, center=true);
    }

    intersection(){
      difference(){
	cylinder(r=globe_ir, h=height, $fn=50);
	translate([0,0,-1])cylinder(r=globe_ir-2, h=height+2, $fn=50);
	rotate([90,0,0])translate([0,8,0])cylinder(d=5, h=30, $fn=30);
	rotate([0, 0, 180+2.6])translate([-200, 0, 3.4])
	  rotate([0, 90, 0])cylinder(d=3.5, h=100, $fn=30);
	rotate([0, 0, 180-2.6])translate([-200, 0, 3.4])
	  rotate([0, 90, 0])cylinder(d=3.5, h=100, $fn=30);
      }
      translate([100,0,0])cube([200, 25, 100], center=true);
    }
  }
}
aov_arm();
//penny_compartment(0);

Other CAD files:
kicad/Ref_Docs/kicad_assets/diode_B130_13_F/SMA_DIO.step
python/antarctica_raised_patch.stl
fabricate/aov_arm_2stack.scad
data/earth_stls/earthmap.blend
fabricate/Custom_Wrench.scad
fabricate/antarctica_orig.scad
fabricate/arduino.scad
fabricate/bearing_shim.scad
fabricate/calibration_jig.scad
fabricate/dynamixel_aov_arm.scad
fabricate/dynamixel_drive_shaft.stl
fabricate/dynamixel_motor.scad
fabricate/dynamixel_xl330_gear_adapter.scad
fabricate/dynamixel_xl330_gear_adapter.stl
fabricate/files/customizable_wrench.scad
fabricate/flange.scad
fabricate/flex_aov_arm.scad
fabricate/full_assembly.scad
fabricate/full_assembly_projection.scad
fabricate/helical_gears.scad
fabricate/inclination_aov_mount.scad
fabricate/inclination_guide.scad
fabricate/iss_simplified_2d.scad
fabricate/m4_wrench.scad
fabricate/monitor_clip.scad
fabricate/north_pole.scad
fabricate/orbigator_pcb.scad
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

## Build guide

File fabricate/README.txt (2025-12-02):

Customizable wrench (standard M3,M4,M5,[...] and custom size) by Noisemaker00 on Thingiverse: https://www.thingiverse.com/thing:2131307

Summary:
This is a customizable wrench. You can:choose the nut sizechoose to have open nut-hole side, closed nut-hole side or boththe wrench ticknessYou can set nut size in two different ways:specify the metric nut size (eg. M4, M4, ... up to M20)specify a custom nut &gt;external&lt; diameter size in mmHow to:1) download OpensCAD2) open my file and follow instructions inside to customize3) click on "Render" (F6)4) click on "STL", save it and print

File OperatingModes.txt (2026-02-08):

ORBIGATOR DESIGN DOC — DUAL HARDWARE / DUAL MODE OPERATION
Version: v0.1
Date: 2026-02-08
Owner: Justin / Orbigator

GOAL
Prevent feature bleed and breakage when switching between two Pico variants:
- Pico 2 W (Wi-Fi capable): supports web-enabled operations.
- Pico 2 (no Wi-Fi): supports offline-only operations.

The system must run on both devices from the same codebase, with deterministic behavior:
- Web features MUST NOT appear (or execute) on Pico 2.
- Offline mode MUST remain stable and fully functional on Pico 2.
- Web-enabled mode MUST retain SGP4 tracking + web server + NTP on Pico 2 W.

NON-GOALS
- No attempt to emulate Wi-Fi in Pico 2.
- No partial web behavior (e.g., “web menu items but not functional”).
- No runtime crashes due to missing modules (network, socket, urequests, etc.).

DEFINITIONS
Hardware Types:
- HW_PICO2W: Raspberry Pi Pico 2 W (Wi-Fi present)
- HW_PICO2:  Raspberry Pi Pico 2 (no Wi-Fi)

Operating Modes (user-visible):
- MODE_WEB_ENABLED: for HW_PICO2W only
- MODE_WEB_DISABLED: for HW_PICO2 only

Feature Sets (capabilities):
- CAP_SGP4_TRACKING
- CAP_WEB_SERVER
- CAP_NTP_TIME_SYNC
- CAP_NETWORKING
- CAP_ORBIT_OFFLINE (offline orbit sim / basic tracking without web)
- CAP_RTC (DS3232 time)
- CAP_MOTOR_CONTROL (Dynamixel)
- CAP_STATE_CACHE (SRAM/flash persistence)

REQUIREMENTS

R1. Single Codebase, Two Builds
- Same repository and directory structure.
- Two build targets (or two runtime paths) must produce:
  - Pico 2 W image: web-enabled features available.
  - Pico 2 image: web-disabled features available.

R2. Capability-Driven Feature Gating (Hard Boundary)
- UI/menu/API must be generated from capabilities, not from “what we think is running.”
- No web server code import/execution path allowed unless CAP_WEB_SERVER is true.
- No NTP sync attempt unless CAP_NTP_TIME_SYNC is true.
- Any feature requiring web access must be behind CAP_NETWORKING true.

R3. Module Import Safety
- On Pico 2, importing Wi-Fi modules must not occur at import-time.
- Wi-Fi and web modules must be imported only inside guarded code paths
  (e.g., inside functions that are called only if CAP_NETWORKING is true).

R4. Deterministic Startup Sequence
Boot pipeline must be stable on both boards:
1) Load configuration
2) Identify hardware + compute capabilities
3) Initialize core subsystems (RTC, cache, motors)
4) Enter operating mode:
   - Pico2W: optionally bring up Wi-Fi and web
   - Pico2: skip network entirely
5) Start selected orbit/tracking behavior

R5. User-Facing Behavior
- Pico2W: exposes SGP4 Tracking Mode, web server toggles, NTP time sync, and all web-backed UX.
- Pico2: exposes offline Orbit Mode only (no web toggles, no NTP options, no “web server” UI).

ARCHITECTURE OVERVIEW

A) Capability Layer (single source of truth)
Create a module: capabilities.py

Responsibility:
- Identify hardware and return a Capabilities object.
- Enforce invariants: HW_PICO2 implies CAP_NETWORKING=False, etc.

Outputs:
- hw_type: HW_PICO2W or HW_PICO2
- caps: set of capabilities booleans
- operating_mode: MODE_WEB_ENABLED or MODE_WEB_DISABLED

B) Feature Modules (separate concerns)
Modules that require networking MUST be isolated:
- web_server.py (only imported/used when CAP_WEB_SERVER)
- ntp_sync.py (only imported/used when CAP_NTP_TIME_SYNC)
- networking.py (Wi-Fi bringup)

Offline modules must never import networking code:
- orbit_offline.py
- motor_control.py
- rtc.py
- state_cache.py

C) Main Orchestrator (boot.py / main.py)
- Boot loads config
- Gets capabilities
- Builds a FeatureRegistry and UI/command surface from capabilities
- Runs chosen mode pipeline

CAPABILITY MODEL

Capabilities object:
- has_wifi: bool
- has_web_server: bool
- has_ntp: bool
- has_sgp4: bool
- has_orbit_offline: bool
- has_rtc: bool
- has_cache: bool
- has_motors: bool

Derived rules (MUST hold):
- HW_PICO2W:
    has_wifi = True
    has_web_server = True (if compiled in)
    has_ntp = True (if compiled in)
    has_sgp4 = True (required)
    has_orbit_offline = True (optional but recommended as fallback)
- HW_PICO2:
    has_wifi = False
    has_web_server = False
    has_ntp = False
    has_sgp4 = False OR True (allowed only if it does not require networking)
    has_orbit_offline = True (required)

Critical invariant:
- Any “web feature” requires has_wifi AND has_web_server.
- Any “time sync via NTP” requires has_ntp AND has_wifi.

HARDWARE IDENTIFICATION STRATEGY

Preferred (robust):
- Detect Wi-Fi capability by attempting safe import:
    try: import network
    except ImportError: no wifi
- Optionally confirm by checking known pins/hardware id, but import-based is simplest.

Do NOT:
- Assume based on config alone.
- Show web UI options on Pico2 even if config contains them.

CONFIGURATION STRATEGY

config.json contains both general settings and optional web settings.

Example schema:
- general:
    - device_name
    - timezone / UTC preference
    - default_mode (requested mode)
- motors:
    - ids, gear ratios, limits, etc.
- orbit:
    - offline orbit mode config (always valid)
- web (optional):
    - enable_web_server (bool)
    - port
    - hostname
    - ntp_server(s)
    - enable_ntp_sync (bool)

Rules:
- On Pico2:
    - web.* keys are ignored (but not deleted).
    - UI never shows web.* settings.
    - no warnings unless debug enabled.
- On Pico2W:
    - web.* keys are honored.

FEATURE REGISTRY (prevents forgetting)

Implement a registry that declares:
- feature name
- required capabilities
- entrypoints (start/stop)
- configuration keys used
- UI elements exposed

Example features:
- Feature: OrbitOffline
  requires: CAP_ORBIT_OFFLINE
- Feature: SGP4Tracking
  requires: CAP_SGP4_TRACKING
- Feature: WebServer
  requires: CAP_WEB_SERVER
- Feature: NTPSync
  requires: CAP_NTP_TIME_SYNC

UI and command surface is built only from “enabled features.”

BOOT FLOWS

FLOW 1: Pico2W (Web Enabled)
1) cap = detect_capabilities() => MODE_WEB_ENABLED
2) init RTC/cache/motors
3) if config.web.enable_ntp_sync: attempt NTP sync (guarded)
4) compute initial satellite state (SGP4)
5) if config.web.enable_web_server: start web server
6) run tracking loop (SGP4 tracking)

FLOW 2: Pico2 (Web Disabled)
1) cap = detect_capabilities() => MODE_WEB_DISABLED
2) init RTC/cache/motors
3) skip Wi-Fi, skip NTP, skip web server
4) run offline orbit mode loop
5) any web config is ignored and never shown

ERROR HANDLING RULES

- If code tries to start a feature without required capabilities: raise a clear error in debug logs and skip feature.
- Never crash at import-time because of missing network modules.
- Network errors on Pico2W (NTP timeouts etc.) must degrade gracefully:
  - proceed with RTC/local time
  - do not block boot indefinitely

TEST PLAN (must be automated or at least scriptable)

T1. Import Safety Test (Pico2)
- Run boot on Pico2 with config containing web options.
- Assert: no ImportError from network modules.
- Assert: no “web server” menu or options shown.
- Assert: orbit offline mode runs.

T2. Capability Boundary Test
- Force config.web.enable_web_server = True on Pico2.
- Assert: web server is NOT started, and no UI shows it.

T3. Pico2W Web Mode Test
- Boot Pico2W with web enabled and NTP enabled.
- Assert: NTP attempt occurs.
- Assert: web server starts.
- Assert: SGP4 tracking mode available.

T4. Pico2W Offline Fallback
- Boot Pico2W with NTP failing.
- Assert: system continues using RTC/local time.
- Assert: tracking still runs.

T5. Regression: Hardware Swap
- Move SD/config between Pico2W and Pico2.
- Both boots must succeed with no manual config edits.

IMPLEMENTATION NOTES (to prevent feature bleed)
- No global “ENABLE_WIFI” constant scattered across files.
- One module owns capability detection and returns a single object.
- Every feature module declares its required caps.
- UI generation is based only on enabled features.

DONE CRITERIA
- Swapping Pico2W <-> Pico2 never exposes invalid options.
- Pico2 never attempts networking, NTP, or web server.
- Pico2W provides web features reliably and degrades gracefully when network is unavailable.
- No import-time failures on Pico2.

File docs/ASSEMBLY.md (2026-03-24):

# Orbigator Assembly Instructions

This guide provides step-by-step instructions for assembling the Orbigator hardware and electronics based on the provided 3D printed parts and bill of materials.

## Prerequisites

Before starting, ensure you have all the parts listed in the [BOM](../README.md#bill-of-materials-bom), including:
*   3D Printed Parts (from `fabricate/stls/Production/`)
*   Electronics (Pico 2W, DYNAMIXEL motors, display, custom PCB/proto-board)
*   Hardware (1010 extruded aluminum stock, screws, M3 magnets, spring arms, globe)

---

## 1. Preparation

1.  **Assign Motor IDs**: Configure and assign the correct IDs to the Angle of View (AoV) and Equatorial (EQX) DYNAMIXEL motors using Dynamixel Wizard or the [appropriate setup script](../software/setup_motors.py).
2.  **3D Printing**: Print all required components from the `fabricate/stls/Production/` directory. Pay attention to the filename prefixes for the required quantities (e.g., `3_swingarm.stl` means print 3 copies).

## 2. Upper Mechanism (AoV)

3.  **Mount AoV Motor**: Attach the AoV motor to the 3D-printed `inclination_aov_mount`.
4.  **Attach Aluminum Stock**: Secure the 1010 extruded aluminum stock to the `inclination_aov_mount` at your target orbital inclination. Since the mount uses 5-degree increments, for the ISS, set this to **50 degrees**.
5.  **Test Fit Height**: Insert the 1010 aluminum stock into the `full_assembly` to verify the fit. You will set the final **73mm clearance** between the `full_assembly` and the inclination mount during the final assembly stage.

## 3. Lower Mechanism (EQX)

6.  **Mount EQX Drive Elements**: Attach the drive shaft and drive gear to the EQX motor.
7.  **Secure EQX Motor**: Fasten the EQX motor to the `full_assembly` using two standard mounting screws.
8.  **Engage Ring Gear**: Engage the EQX ring gear with the drive gear. Fasten the assembly together using the 3x printed spring arms and 3D printed washers to ensure proper tension and alignment.

## 4. Electronics Assembly

9.  **Prepare the Board**: Solder female headers onto the main board to socket the Raspberry Pi Pico 2W, the OLED display/encoder, and the motor connections.
10. **Mount Electronics**: Attach the completed electronics assembly unit using 4x screws to its designated housing or base `sled_3`.
11. **Route Cables**: 
    *   Thread the EQX motor cable through the center hole. *(Note: You may need to temporarily remove the 1010 aluminum stock to do this. If removed, reinsert it and verify the 73mm spacing is maintained).*
    *   Attach the AoV motor cable to the EQX motor pass-through to daisy-chain the data and power.

## 5. Final Assembly & Calibration

12. **Assemble the Pointer**: Embed the M3 magnets into the AoV arm, then attach the AoV arm directly to the AoV motor.
13. **Program the Pico 2W**: Flash the MicroPython firmware and upload the project code to the Pico 2W.
14. **System Test**: Run initial tests (e.g., `tests/motion_test.py` and `tests/test_motors.py`) to verify motor communication, movement, and display functionality.
15. **Globe Installation**: Run the homing sequence to move the motors to their zero positions. Once homed, carefully add the globe and the globe interface mount to complete the build!

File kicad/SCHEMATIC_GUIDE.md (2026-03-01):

# Orbigator Schematic Creation Guide for KiCad 8.x

This guide will help Anool quickly create the Orbigator schematic in KiCad.

## Prerequisites

- KiCad 8.x installed
- All reference documentation reviewed:
  - `ORBIGATOR_CIRCUIT_DIAGRAM.txt`
  - `ORBIGATOR_PIN_ASSIGNMENTS.txt`
  - `NOTE_FOR_ANOOL_I2C_PULLUPS.txt`
  - `bom/BOM.md`
  - `NETLIST.md`

## Step 1: Open the Project

1. Open KiCad
2. File → Open Project
3. Select `orbigator.kicad_pro`

## Step 2: Create the Schematic

1. Click "Schematic Editor" button
2. The schematic will be blank - we'll build it from scratch

## Step 3: Place Components

### Power Symbols
1. Press `P` to place power symbols
2. Add the following:
   - `+5V` (external supply)
   - `+3V3` (from Pico)
   - `GND` (common ground)

### Main Components

Place each component using `A` (Add Symbol):

#### U1 - Raspberry Pi Pico 2
- Library: `MCU_Module`
- Symbol: `Raspberry_Pi_Pico_2`
- Reference: `U1`
- Value: `Pico 2`

#### U2 - 74HC126
- Library: `74xx`
- Symbol: `74HC126`
- Reference: `U2`
- Value: `74HC126`

#### DISP1 - OLED Display
- Library: `Display`
- Symbol: `OLED_128x64_I2C`
- Reference: `DISP1`
- Value: `SSD1306`

#### RTC1 - DS3232
- Library: `Timer_RTC`
- Symbol: `DS3232MZ`
- Reference: `RTC1`
- Value: `DS3232`

#### M1, M2 - DYNAMIXEL Motors
- Library: `Connector`
- Symbol: `Conn_01x03`
- References: `M1`, `M2`
- Values: `DYNAMIXEL_1`, `DYNAMIXEL_2`
- Note: Add labels for GND, VDD, DATA

#### ENC1 - Rotary Encoder
- Library: `Device`
- Symbol: `Rotary_Encoder_Switch`
- Reference: `ENC1`
- Value: `Encoder`

### Passive Components

- `R1`: 10kΩ (DATA bus pull-up)
- `R2`: 4.7kΩ (I2C SDA pull-up)
- `R3`: 4.7kΩ (I2C SCL pull-up)

### Connectors

#### J1 - Power Input
- Library: `Connector`
- Symbol: `Barrel_Jack`
- Reference: `J1`
- Value: `5V_IN`

#### J2 - DYNAMIXEL Connector
- Library: `Connector`
- Symbol: `Conn_01x03`
- Reference: `J2`
- Value: `DYNAMIXEL_BUS`

#### J3 - Encoder Connector
- Library: `Connector`
- Symbol: `Conn_01x05`
- Reference: `J3`
- Value: `ENCODER`

## Step 4: Wire the Schematic

Use `W` (Wire tool) to connect components according to `NETLIST.md`.

### Critical Connections

#### Power Distribution
1. Connect J1 Pin 1 (+) to `+5V` net
2. Connect J1 Pin 2 (-) to `GND` net
3. Connect Pico Pin 36 (3V3_OUT) to `+3V3` net
4. Connect all GND pins together

#### UART & Buffer (Half-Duplex)
1. Pico GP0 (Pin 1) → 74HC126 Pin 2 (1A)
2. 74HC126 Pin 3 (1Y) → DATA_BUS net
3. Pico GP1 (Pin 2) → DATA_BUS net
4. Pico GP2 (Pin 4) → 74HC126 Pin 1 (1OE)
5. DATA_BUS → M1 Pin 3, M2 Pin 3, J2 Pin 3
6. R1 Pin 1 → +5V, R1 Pin 2 → DATA_BUS

#### I2C Bus (CRITICAL - Needs Pull-ups!)
1. Pico GP4 (Pin 6) → I2C_SDA net
2. Pico GP5 (Pin 7) → I2C_SCL net
3. I2C_SDA → DISP1 SDA, RTC1 SDA
4. I2C_SCL → DISP1 SCL, RTC1 SCL
5. R2 Pin 1 → +3V3, R2 Pin 2 → I2C_SDA
6. R3 Pin 1 → +3V3, R3 Pin 2 → I2C_SCL

#### Encoder
1. Pico GP6 (Pin 9) → ENC1 Pin A
2. Pico GP7 (Pin 10) → ENC1 Pin B
3. Pico GP8 (Pin 11) → ENC1 Pin SW
4. ENC1 VCC → +3V3
5. ENC1 GND → GND

#### RTC Backup Power
1. Connect CR2032 (+) to RTC1 `V_BAT` pin
2. Connect CR2032 (-) to `GND`

#### Motor Power
1. +5V → M1 Pin 2 (VDD), M2 Pin 2 (VDD), J2 Pin 2
2. GND → M1 Pin 1, M2 Pin 1, J2 Pin 1

## Step 5: Add Labels and Annotations

1. Use `L` (Label tool) to add net labels:
   - `+5V`, `+3V3`, `GND`
   - `DATA_BUS`
   - `I2C_SDA`, `I2C_SCL`
   - `UART_TX`, `UART_RX`, `DIR_PIN`
   - `ENC_A`, `ENC_B`, `ENC_SW`

2. Add text notes (Press `T`):
   - "CRITICAL: I2C pull-ups required!" near R2/R3
   - "10kΩ to +5V" near R1

## Step 6: Assign Footprints

1. Tools → Assign Footprints
2. Use the footprints from `bom/BOM.md`
3. Key footprints:
   - U1: `Module:Raspberry_Pi_Pico_SMD`
   - U2: `Package_DIP:DIP-14_W7.62mm`
   - R1-R3: `Resistor_THT:R_Axial_DIN0207_L6.3mm_D2.5mm_P10.16mm_Horizontal`

## Step 7: Run Electrical Rules Check (ERC)

1. Inspect → Electrical Rules Checker
2. Click "Run ERC"
3. Fix any errors (should be clean if wired correctly)

## Step 8: Generate Netlist

1. File → Export → Netlist
2. Save as `orbigator.net`
3. This will be used for PCB layout

## Step 9: Create PCB Layout

1. Click "PCB Editor" button
2. Tools → Update PCB from Schematic
3. Click "Update PCB"
4. All components will appear - ready for placement and routing

## Layout Tips

### Component Placement
- Place Pico in center
- Group I2C devices (OLED, RTC) near Pico GP4/GP5
- Place 74HC126 near Pico GP0/GP1/GP2
- Place motor connectors on edge for cable access
- Place encoder connector on accessible edge

### Routing Priority
1. Power traces first (+5V, +3V3, GND)
   - Use 1.0mm for +5V (motor current)
   - Use 0.5mm for +3V3
   - Use ground pour on bottom layer
2. I2C traces (keep short!)
3. UART/DATA_BUS
4. Encoder signals

### Design Rules
- Minimum trace: 0.25mm
- Minimum clearance: 0.2mm
- Power traces: 1.0mm
- Via: 0.8mm diameter, 0.4mm drill

## Step 10: Generate Gerbers

1. File → Plot
2. Output directory: `gerber/`
3. Layers to plot:
   - F.Cu, B.Cu
   - F.SilkS, B.SilkS
   - F.Mask, B.Mask
   - Edge.Cuts
4. Click "Plot"
5. Click "Generate Drill Files"

## Step 11: Export BOM

1. Tools → Generate BOM
2. Select CSV format
3. Save to `bom/` directory

## Step 12: Create PDF Schematic

1. File → Plot
2. Select "PDF" format
3. Output to `pdf/` directory

## Verification Checklist

- [ ] All components placed
- [ ] All nets connected (no airwires)
- [ ] I2C pull-ups (R2, R3) present and correct
- [ ] DATA bus pull-up (R1) to +5V
- [ ] RTC Backup Battery (BAT1) connected
- [ ] ERC passes with no errors
- [ ] Footprints assigned
- [ ] PCB layout complete
- [ ] DRC passes
- [ ] Gerbers generated

## Common Issues

### I2C Not Working
- Check R2, R3 are 4.7kΩ to +3.3V (NOT +5V!)
- Verify SDA/SCL connections to GP4/GP5

### DYNAMIXEL Not Responding
- Check R1 is 10kΩ to +5V (NOT +3.3V!)
- Verify 74HC126 direction control (GP2 → 1OE)

### RTC Losing Time
- Check battery voltage (CR2032)
- Verify `V_BAT` connection

## Need Help?

Refer to:
- `ORBIGATOR_CIRCUIT_DIAGRAM.txt` - ASCII circuit diagram
- `NETLIST.md` - Complete connection list
- `bom/BOM.md` - Component specifications

Good luck! The schematic should take 1-2 hours to complete.

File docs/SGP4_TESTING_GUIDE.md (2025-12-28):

# SGP4 Integration - Testing Guide

## Current Status (Dec 25, 2024)

### ✅ Completed
- SGP4 propagator integrated into Orbigator
- Satellite catalog created (ISS, Hubble, Tiangong, Starlink)
- TLE caching and WiFi fetching working
- Menu system updated with "Track Satellite" option
- GMST calculation for accurate geodetic conversion
- **Critical bug fixed**: Added missing epoch_year/epoch_day variables

### 🔧 Files Modified
- `micropython/modes.py` - Added SGP4Mode class
- `micropython/orb_utils.py` - Added GMST and TLE utilities
- `micropython/satellite_catalog.py` - NEW
- `micropython/tle_cache.json` - NEW

### 🐛 Bugs Fixed
1. **WiFi connection** - Changed from `wifi_setup.connect()` to `wifi_setup.connect_wifi(ssid, password)`
2. **Epoch calculation** - Implemented proper TLE epoch → Unix timestamp conversion
3. **Variable scope** - Added missing `epoch_year` and `epoch_day` variable definitions

## Testing Instructions for Tomorrow

### Step-by-Step Test

1. **Power on Orbigator**
   - Should boot normally to menu

2. **Navigate to SGP4 Mode**
   - Menu → "Track Satellite" (2nd item)

3. **Select Satellite**
   - Rotate encoder to choose: ISS / Hubble / Tiangong / Starlink
   - Display shows satellite name and TLE age

4. **Start Tracking** ⚠️ CRITICAL STEP
   - **Press the ENCODER BUTTON** (push the rotary encoder)
   - Should print: "Tracking ISS" (or selected satellite)
   - Motors should immediately move to satellite position

5. **Verify Real-Time Tracking**
   - Display should show:
     - Satellite name
     - Current lat/lon/alt
     - TLE age
   - Motors should continuously update position
   - For ISS: longitude should change ~4°/minute

### Button Functions in SGP4 Mode

| Button | Function |
|---|---|
| **Encoder Rotate** | Select satellite (ISS/Hubble/Tiangong/Starlink) |
| **Encoder Press** | ⭐ **Toggle tracking ON/OFF** |
| **Confirm** | Force TLE refresh via WiFi |
| **Back** | Return to main menu |

### Expected Behavior

**ISS Tracking:**
- Latitude: -51.6° to +51.6° (oscillating, ~90 min period)
- Longitude: Continuously increasing, ~4°/minute
- Altitude: ~400-420 km
- AoV motor: Follows latitude (0° to 180° range)
- EQX motor: Follows longitude (0° to 360° range)

### Troubleshooting

**If motors don't move:**
1. Check if "Tracking ISS" printed (confirms encoder press worked)
2. Check display shows lat/lon updating
3. Look for error messages in output
4. Verify motors respond in normal "Orbit!" mode

**If position doesn't update:**
1. Check for NameError or other Python errors
2. Verify epoch calculation is working
3. Check RTC time is correct

**If TLE fetch fails:**
1. Verify `wifi_config.json` exists
2. Check WiFi credentials
3. Cached TLEs will still work for tracking

## Code Locations

### SGP4Mode Class
File: `micropython/modes.py`
- Lines ~685-924
- Key methods:
  - `enter()` - Initialize mode, load TLEs
  - `_load_satellite(index)` - Parse TLE and init SGP4
  - `_fetch_tle()` - WiFi TLE refresh
  - `update(dt)` - **Real-time position calculation**
  - `on_encoder_press()` - Toggle tracking

### Epoch Calculation (Fixed)
File: `micropython/modes.py`, lines 850-868
```python
# Get epoch from SGP4 object
epoch_year = self.sgp4.epoch_year
epoch_day = self.sgp4.epoch_day

# Convert TLE epoch to Unix timestamp
epoch_jan1 = time.mktime((epoch_year, 1, 1, 0, 0, 0, 0, 0))
epoch_timestamp = epoch_jan1 + (epoch_day - 1.0) * 86400.0

# Calculate minutes since TLE epoch
elapsed_sec = now - epoch_timestamp
t_min = elapsed_sec / 60.0
```

## Next Steps

### If Tracking Works ✅
- Test with different satellites (Hubble, Tiangong)
- Verify TLE auto-refresh after 24 hours
- Test mode transitions (SGP4 → Menu → Orbit → SGP4)
- Confirm baseline "Orbit!" mode still works

### If Issues Remain 🐛
- Check for Python errors in output
- Verify `self.tracking` flag is set
- Add debug prints to `update()` method
- Test SGP4 propagator standalone with `test_sgp4_simple.py`

## Files Ready for Upload

All files are already on the Pico 2W:
- ✅ `modes.py` (with all fixes)
- ✅ `orb_utils.py` (with GMST)
- ✅ `satellite_catalog.py`
- ✅ `tle_cache.json`
- ✅ `sgp4.py`
- ✅ `tle_fetch.py`

Just power on and test!

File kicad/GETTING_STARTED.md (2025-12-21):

# Getting Started Guide for Anool

## Your First Steps

### 1. Open the Project ✅ (Ready to go!)

```bash
cd kicad/
# Open orbigator.kicad_pro in KiCad
```

The project is already set up with:
- ✅ Board outline (55×70mm, rotated and centered)
- ✅ Mounting holes (4× M3, correctly positioned)
- ✅ Design rules configured
- ✅ Empty schematic ready for components

### 2. Create the Schematic (Start Here!)

Open the Schematic Editor and follow `SCHEMATIC_GUIDE.md`:

**Quick Start:**
1. Press `A` to add symbols
2. Start with power symbols: `+5V`, `+3V3`, `GND`
3. Add main components (see component list below)
4. Wire according to `NETLIST.md`
5. Run ERC (Inspect → Electrical Rules Checker)

**Component List (in order):**
```
U1: Raspberry_Pi_Pico_2 (MCU_Module)
U2: 74HC126 (74xx)
DISP1: OLED_128x64_I2C (Display)
RTC1: DS3231M (Timer_RTC)
M1, M2: Conn_01x03 (Connector) - DYNAMIXEL motors
ENC1: Rotary_Encoder_Switch (Device)
R1-R4: R (Device) - Resistors
C1: CP (Device) - Supercapacitor
C2-C3: C (Device) - Capacitors
J1: Barrel_Jack (Connector)
J2: Conn_01x03 (Connector) - DYNAMIXEL bus
J3: Conn_01x05 (Connector) - Encoder
```

### 3. Assign Footprints

After schematic is complete:
1. Tools → Assign Footprints
2. Use footprints from `bom/BOM.md`
3. Critical footprints:
   - U1: `Module:Raspberry_Pi_Pico_SMD`
   - U2: `Package_DIP:DIP-14_W7.62mm`
   - C1: `Capacitor_THT:CP_Radial_D10.0mm_P5.00mm`

### 4. Update PCB from Schematic

1. Open PCB Editor
2. Tools → Update PCB from Schematic (F8)
3. Click "Update PCB"
4. All components will appear - ready for placement!

### 5. Place Components

Follow the placement guidelines in `PCB_CHECKLIST.md`:
- Pico in center
- I2C devices near GP4/GP5
- Buffer near GP0/GP1/GP2
- Connectors on edges

### 6. Route the Board

Priority order:
1. Power traces (+5V, +3.3V, GND)
2. I2C bus (keep short!)
3. UART/DATA_BUS
4. Encoder signals

Use `QUICK_REFERENCE.md` for trace widths.

### 7. Run DRC

1. Inspect → Design Rules Checker
2. Fix all errors (must be 0 errors)
3. Review warnings

### 8. Generate Manufacturing Files

1. File → Plot
2. Select Gerber format
3. Output to `gerber/` directory
4. Generate drill files
5. Zip everything for manufacturer

---

## Estimated Time

- Schematic: 1-2 hours
- Component placement: 30 minutes
- Routing: 2-3 hours
- DRC and fixes: 30 minutes
- **Total: 4-6 hours**

## Need Help?

**Documentation:**
- `SCHEMATIC_GUIDE.md` - Step-by-step schematic creation
- `PCB_CHECKLIST.md` - Complete design checklist
- `QUICK_REFERENCE.md` - Critical info at a glance
- `DESIGN_RULES.md` - All design constraints
- `bom/BOM.md` - Component specifications
- `NETLIST.md` - Connection details

**Critical Notes:**
- `../NOTE_FOR_ANOOL_I2C_PULLUPS.txt` - I2C pull-up requirements
- `../ORBIGATOR_CIRCUIT_DIAGRAM.txt` - ASCII circuit diagram
- `../ORBIGATOR_PIN_ASSIGNMENTS.txt` - Pin assignments

## Common First-Time Issues

### "I can't find a component in the library"
- Make sure you're searching the right library (shown in parentheses)
- Try searching without the full part number
- Example: Search "Pico" not "Raspberry_Pi_Pico_2"

### "Footprint assignment failed"
- Check that the footprint library is installed
- Use the exact footprint names from `bom/BOM.md`
- Update footprint libraries if needed

### "ERC shows errors"
- Most common: Missing power connections
- Check that all power pins are connected
- Verify pull-ups are connected correctly

### "Components won't update to PCB"
- Make sure schematic has no ERC errors
- Save schematic before updating PCB
- Try "Update PCB from Schematic" again

## Pro Tips

1. **Save often!** KiCad auto-saves but manual saves are safer
2. **Use net labels** - Makes schematic cleaner and easier to read
3. **Group related components** - Easier to route later
4. **Check footprints early** - Easier to fix in schematic than PCB
5. **Use the checklist** - Don't skip steps!

## Ready to Start?

1. Open `orbigator.kicad_pro`
2. Click "Schematic Editor"
3. Follow `SCHEMATIC_GUIDE.md`
4. Reference `QUICK_REFERENCE.md` for critical values

**Good luck! You've got this! 🚀**

---

Questions? Check the documentation or reach out to Justin.

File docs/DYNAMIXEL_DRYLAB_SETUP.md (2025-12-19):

# DYNAMIXEL Motor Setup - Dry Lab Walkthrough

## 🎯 Overview
This guide walks you through setting up your DYNAMIXEL XL330-M288-T motors for the Orbigator project. Since the motors arrived with self-tapping screws (bonus!), we can skip sourcing those.

---

## 📦 Parts Inventory Check

### What You Should Have:
- ✅ **2× DYNAMIXEL XL330-M288-T servos** (just arrived!)
- ✅ **Self-tapping screws** (came with motors)
- ✅ **1× SN74HC126N tri-state buffer IC**
- ✅ **1× 10kΩ resistor** (pull-up for DATA line)
- ✅ **1× Raspberry Pi Pico 2**
- ✅ **1× 5V 4-5A power supply** (for servos)
- ✅ **Breadboard and jumper wires**
- ✅ **3D printed drive shaft adapter** (currently printing with updated dimensions)

---

## 🔧 Phase 1: Initial Inspection & Preparation

### 1.1 Identify Wire Pins (Wires Not Color-Coded!)
**IMPORTANT:** Your motors have unmarked wires. Identify pins BEFORE connecting power!

See [`DYNAMIXEL_PIN_DIAGRAM.md`](file:///home/justin/.gemini/antigravity/brain/357765be-9559-47f3-8ceb-0ed9de1921a9/DYNAMIXEL_PIN_DIAGRAM.md) for detailed instructions.

**CRITICAL: Connectors are MIRRORED!** Pin 1 (GND) is always on the outer edge:

DYNAMIXEL Official Pinout from ROBOTIS e-Manual

**Quick method using multimeter:**
- [ ] Set multimeter to continuity mode
- [ ] Touch one probe to motor case/mounting holes
- [ ] Touch other probe to each wire
- [ ] The wire that beeps = **GND (Pin 1)** - always on outer edge!
- [ ] Label with black tape: "GND"
- [ ] Middle pin = **VDD (+5V)** - label with red tape
- [ ] Inner pin = **DATA** - label with yellow tape

### 1.2 Inspect the Motors
- [ ] Unpack both DYNAMIXEL servos
- [ ] Verify the horn thickness (you mentioned it's thinner than expected)
- [ ] Check that both motors have:
  - Two 3-pin JST connectors (one on each side - both identical!)
  - White output horn attached
  - Mounting holes visible on sides
- [ ] Inventory the self-tapping screws that came with them

### 1.2 Measure Horn Dimensions
Since you found the horn is thinner than expected:
- [ ] Measure actual horn height with calipers
- [ ] Update `horn_height` in `dynamixel_motor.scad` if needed
- [ ] Note: Current model has `horn_height = 2.8` mm (line 19)
- [ ] If different, update and re-render drive shaft adapter

### 1.3 Test Drive Shaft Fit (After Print Completes)
- [ ] Let drive shaft print finish
- [ ] Test fit on motor horn (should be snug)
- [ ] Verify mounting holes align with horn holes
- [ ] Check that D-shaft profile is correct

---

## ⚡ Phase 2: Electrical Setup

### 2.1 Gather Electronic Components
- [ ] SN74HC126N IC
- [ ] 10kΩ resistor
- [ ] Breadboard
- [ ] Jumper wires (various colors for organization)
- [ ] Raspberry Pi Pico 2
- [ ] 5V power supply with appropriate connector

### 2.2 Understanding the 74x126 Tri-State Buffer

The **SN74HC126N** (or 74x126 family) is a quad tri-state buffer that enables half-duplex communication with DYNAMIXEL servos. We only use one of the four buffers (gate 1).

74x126 Pinout Diagram

#### Why Do We Need This?

DYNAMIXEL servos use **half-duplex UART** - a single DATA wire for both transmit (TX) and receive (RX). The Pico has separate TX and RX pins, so we need the buffer to:
1. **Connect Pico TX to DATA** when transmitting (buffer enabled)
2. **Disconnect Pico TX from DATA** when receiving (buffer tri-stated/high-Z)
3. **Allow Pico RX to always listen** on DATA line

#### Pin Functions (14-pin DIP):

| Pin | Name | Function | Connection |
|-----|---|---|---|
| 1 | 1OE | Output Enable (Gate 1) | GP2 (Direction Control) |
| 2 | 1A | Input (Gate 1) | GP0 (UART TX) |
| 3 | 1Y | Output (Gate 1) | DATA BUS |
| 4 | 2OE | Output Enable (Gate 2) | Not used |
| 5 | 2A | Input (Gate 2) | Not used |
| 6 | 2Y | Output (Gate 2) | Not used |
| 7 | GND | Ground | GND rail |
| 8 | 3Y | Output (Gate 3) | Not used |
| 9 | 3A | Input (Gate 3) | Not used |
| 10 | 3OE | Output Enable (Gate 3) | Not used |
| 11 | 4Y | Output (Gate 4) | Not used |
| 12 | 4A | Input (Gate 4) | Not used |
| 13 | 4OE | Output Enable (Gate 4) | Not used |
| 14 | VCC | Power Supply | 3.3V from Pico |

#### How It Works:

```
Direction Control (GP2):
  HIGH (1) → Buffer ENABLED  → 1Y outputs 1A signal → Pico transmits to DATA
  LOW  (0) → Buffer TRI-STATE → 1Y is high-Z       → Servo transmits on DATA

Pico RX (GP1) is always connected to DATA to receive responses.
```

### 2.3 Build the Interface Circuit

**Reference:** See `DYNAMIXEL_WIRING_DIAGRAM.txt` for complete ASCII diagram

#### Step-by-step wiring:

**A. Place the 74HC126 on breadboard:**
```
Pin 1  (1OE)  ← GP2 (Direction Control)
Pin 2  (1A)   ← GP0 (UART TX)
Pin 3  (1Y)   → DATA BUS
Pin 7  (GND)  ← GND
Pin 14 (VCC)  ← 3.3V from Pico
```

**B. Create the DATA BUS:**
- [ ] Connect 74HC126 Pin 3 to a breadboard rail (this is DATA)
- [ ] Connect GP1 (Pico RX) to same DATA rail
- [ ] Add 10kΩ resistor from DATA rail to 5V rail (pull-up)

**C. Power connections:**
- [ ] Connect Pico GND to breadboard GND rail
- [ ] Connect Pico 3.3V to breadboard 3.3V rail (for 74HC126)
- [ ] Connect external 5V supply GND to breadboard GND rail
- [ ] Connect external 5V supply +5V to breadboard 5V rail

**D. Verify before connecting servos:**
- [ ] Double-check all connections against diagram
- [ ] Ensure common ground between Pico and 5V supply
- [ ] Verify 74HC126 has 3.3V on pin 14
- [ ] Verify DATA line has 10kΩ pull-up to 5V

---

## 🆔 Phase 3: Configure Servo IDs (ONE AT A TIME!)

> **CRITICAL:** Only connect ONE servo at a time during ID configuration!

### 3.1 Upload Setup Script to Pico
- [ ] Connect Pico to computer via USB
- [ ] Copy `micropython/dynamixel_setup.py` to Pico
- [ ] Open Thonny or your preferred MicroPython IDE
- [ ] Verify script is on Pico

### 3.2 Configure First Servo (EQX Motor - ID 1)

**Connect ONLY the first servo:**
- [ ] Take ONE servo
- [ ] Connect its 3-pin JST connector:
  - Black wire → GND rail
  - Red wire → 5V rail
  - Yellow wire → DATA rail
- [ ] Power on the 5V supply
- [ ] Power on the Pico

**Run configuration:**
```python
# In Thonny/REPL
from dynamixel_setup import *

# Scan to find current ID
scan_servos()
# Note the ID it reports (probably 1 if factory default)

# If not ID 1, change it:
change_id(current_id, 1)

# Verify
ping(1)
# Should respond with model and firmware info
```

- [ ] Mark this servo with tape/label: "EQX - ID 1"
- [ ] Disconnect servo from power

### 3.3 Configure Second Servo (AOV Motor - ID 2)

**Disconnect first servo, connect second:**
- [ ] Disconnect first servo completely
- [ ] Connect second servo to same DATA/5V/GND rails
- [ ] Power on

**Run configuration:**
```python
# Scan for this servo
scan_servos()

# Change to ID 2
change_id(current_id, 2)

# Verify
ping(2)
```

- [ ] Mark this servo with tape/label: "AOV - ID 2"
- [ ] Disconnect servo

---

## 🔌 Phase 4: Daisy-Chain Connection

Now both servos have unique IDs, connect them together:

### 4.1 Wire Both Servos
- [ ] Connect Servo 1 (ID 1 - LAN) to breadboard:
  - Black → GND
  - Red → 5V
  - Yellow → DATA
- [ ] Connect Servo 2 (ID 2 - AOV) to same rails:
  - Black → GND (shared)
  - Red → 5V (shared)
  - Yellow → DATA (shared)

### 4.2 Verify Communication
```python
# Scan should find both
scan_servos()
# Should report: Found servo at ID 1, Found servo at ID 2

# Ping each individually
ping(1)
ping(2)

# Both should respond!
```

---

## 🧪 Phase 5: Functional Testing

### 5.1 Basic Movement Test
```python
# Test Servo 1 (EQX Motor)
set_torque(1, True)
set_position(1, 2048)  # Center position
time.sleep(1)
read_position(1)

set_position(1, 1024)  # Quarter turn
time.sleep(1)
read_position(1)

set_position(1, 3072)  # Three-quarter turn
time.sleep(1)
read_position(1)

# Disable torque (motor can be moved by hand)
set_torque(1, False)
```

### 5.2 Test Second Motor
```python
# Test Servo 2 (AOV Motor)
set_torque(2, True)
set_position(2, 2048)
time.sleep(1)
read_position(2)

# Try different position
set_position(2, 0)
time.sleep(1)
read_position(2)

set_torque(2, False)
```

### 5.3 Test Both Simultaneously
```python
# Enable both
set_torque(1, True)
set_torque(2, True)

# Move both to center
set_position(1, 2048)
set_position(2, 2048)
time.sleep(2)

# Move in opposite directions
set_position(1, 1024)
set_position(2, 3072)
time.sleep(2)

# Verify positions
read_position(1)
read_position(2)
```

---

## 🔩 Phase 6: Mechanical Assembly

### 6.1 Install Drive Shaft Adapter
Once your 3D print completes:

- [ ] Remove horn from Servo 1 (if needed for access)
- [ ] **CRITICAL: Check screw length!**
  - Measure horn height with calipers (should be ~2.8mm)
  - Adapter base is 3.2mm thick
  - **Maximum safe screw length = adapter_base + horn_height - 0.5mm safety margin**
  - For default values: 3.2 + 2.8 - 0.5 = **5.5mm max**
  - ⚠️ **Screws longer than this will bottom out on motor body and cause damage!**
- [ ] Place drive shaft adapter over horn
- [ ] Align mounting holes (4 holes at 90° intervals)
- [ ] Insert self-tapping screws through adapter into horn
- [ ] Tighten screws evenly until snug (don't over-torque!)
- [ ] **Stop immediately if screw bottoms out** - use shorter screws
- [ ] Verify adapter is secure and centered

### 6.2 Test Mechanical Range
```python
# Enable torque
set_torque(1, True)

# Slowly sweep through range
for pos in range(0, 4096, 100):
    set_position(1, pos)
    time.sleep(0.1)
    
# Check for binding or mechanical issues
set_torque(1, False)
```

### 6.3 Mount to Orbigator Frame
- [ ] Position motor in Orbigator assembly
- [ ] Use mounting holes on motor body (16mm × 30mm spacing)
- [ ] Secure with appropriate screws/standoffs
- [ ] Verify motor can rotate freely
- [ ] Check cable routing (don't pinch wires!)

---

## 📊 Phase 7: Calibration & Integration

### 7.1 Find Physical Limits
```python
# With motor mounted, find mechanical limits
set_torque(1, True)

# Slowly move to find min position
# Watch for mechanical stops!
set_position(1, 0)

# Find max position
set_position(1, 4095)

# Record actual usable range for your assembly
```

### 7.2 Map to Orbital Parameters
For Orbigator, you need to map servo positions to orbital angles:

### **Quick Reference:**
- Servo 1 (ID=1): **EQX Motor** (Equator crossing)
- Servo 2 (ID=2): **AoV Motor** (Argument of Vehicle - orbital position)
  - 0° = Satellite crosses equator northbound
  - 90° = Maximum latitude
  - 180° = Satellite crosses equator southbound
  - 270° = Minimum latitude

```python
def angle_to_position(angle_deg):
    """Convert angle (0-360°) to servo position (0-4095)"""
    return int((angle_deg / 360.0) * 4095)

def position_to_angle(position):
    """Convert servo position to angle"""
    return (position / 4095.0) * 360.0

# Test
set_position(1, angle_to_position(90))   # 90° LAN
set_position(2, angle_to_position(180))  # 180° AOV
```

### 7.3 Update Orbigator Code
Replace stepper motor functions with DYNAMIXEL commands:

**Old:** `lan_move_steps(steps)`  
**New:** `lan_set_angle(angle_deg)`

**Old:** `aov_move_steps(steps)`  
**New:** `aov_set_angle(angle_deg)`

---

## ✅ Final Checklist

### Electrical
- [ ] Both servos respond to ping
- [ ] IDs are correct (1 and 2)
- [ ] No communication errors
- [ ] Direction control working (GP2)
- [ ] Pull-up resistor in place

### Mechanical
- [ ] Drive shaft adapter fits properly
- [ ] Screws secure (self-tapping worked!)
- [ ] No binding in rotation
- [ ] Motors mounted to frame
- [ ] Cables routed safely

### Software
- [ ] `dynamixel_setup.py` working
- [ ] Can read positions
- [ ] Can set positions
- [ ] Torque enable/disable works
- [ ] Both motors respond independently

### Integration
- [ ] Orbital angle mapping defined
- [ ] Orbigator code updated
- [ ] Calibration values recorded
- [ ] Ready for orbital calculations!

---

## 🚨 Troubleshooting

### No Response from Servo
- Check power (5V supply on?)
- Verify DATA line pull-up (10kΩ to 5V)
- Check direction control (GP2 toggling?)
- Try different baud rate (default 57600)

### Wrong ID Detected
- Only one servo connected during ID change?
- Use `scan_servos()` to find current ID
- Use `change_id(old, new)` to fix

### Mechanical Binding
- Check drive shaft adapter alignment
- Verify screws not over-tightened
- Ensure no interference with frame
- Test with torque disabled (manual rotation)

### Communication Errors
- Verify common ground
- Check 74HC126 wiring
- Ensure UART pins correct (GP0=TX, GP1=RX)
- Try lower baud rate

---

## 📚 Reference Documents

- `ORBIGATOR_COMPLETE_WIRING.txt` - Full system wiring
- `DYNAMIXEL_WIRING_DIAGRAM.txt` - ASCII circuit diagram  
- `DYNAMIXEL_Quick_Reference.md` - One-page cheat sheet
- `micropython/dynamixel_setup.py` - Configuration script
- `fabricate/dynamixel_motor.scad` - 3D model

---

**Good luck with your setup! The motors are going to be perfect for precise orbital positioning! 🚀**

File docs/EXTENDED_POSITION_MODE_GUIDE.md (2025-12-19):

# Extended Position Mode - Best Practices Guide

## 🎯 Overview

Extended Position Control Mode (Mode 4) is the **recommended mode** for Orbigator's continuous orbital tracking. This guide covers the best practices for using it effectively.

---

## ✅ The Recommended Approach

### 1. **Set Mode 4 Once and Leave It**

Configure both motors for Extended Position Mode during initial setup and **never switch back**:

```python
from dynamixel_extended_utils import set_extended_mode

# One-time setup (or after factory reset)
set_extended_mode(1)  # EQX motor
set_extended_mode(2)  # AoV motor
```

**Why?** 
- No need to switch modes for different operations
- Simpler code and fewer potential errors
- Motors remember the mode setting even after power cycle

---

### 2. **Read Position on Every Boot**

**CRITICAL:** Before sending any Goal Position commands, read the current position:

```python
from dynamixel_extended_utils import orbigator_init

# On boot/startup
lan_position, aov_position = orbigator_init()

# Use these as your baseline for all subsequent movements
```

**Why?**
- Prevents motor from jumping to old position values
- Maintains continuity across power cycles
- Essential for accurate orbital tracking

**What happens if you skip this?**
If you power on and immediately send `Goal Position = 0`, the motor will rapidly spin back to position 0, potentially causing:
- Mechanical stress
- Loss of orbital tracking accuracy
- Unexpected behavior

---

### 3. **Don't Worry About Integer Overflow**

Extended Position Mode uses a **signed 32-bit integer**:
- Range: ±2,147,483,647 ticks
- At 1° every 10 seconds: **62+ years** to overflow
- For Orbigator: Effectively infinite

**Conclusion:** Ignore overflow concerns. Your motors will wear out long before the counter overflows.

---

### 4. **Optional: Clear Multi-Turn Command**

If you need to reset the position counter (e.g., after months of operation), use the **Clear Multi-Turn** command:

```python
from dynamixel_extended_utils import clear_multi_turn, read_present_position

# Read current position
old_pos = read_present_position(1)
print(f"Before clear: {old_pos}")

# Clear multi-turn (motor stays in place!)
clear_multi_turn(1)

# Read new position (will be 0-4095)
new_pos = read_present_position(1)
print(f"After clear: {new_pos}")
```

**How it works:**
- Motor shaft **does not move**
- Internal `Present Position` resets to equivalent value within 0-4095 range
- Based on current physical orientation

**When to use:**
- After extended operation (months/years)
- When you want a fresh baseline
- For maintenance/calibration

**When NOT to use:**
- During normal operation
- On every boot (use `read_present_position` instead)
- As a workaround for other issues

---

## 📋 Complete Initialization Checklist

### One-Time Setup (Initial Configuration)

```python
from dynamixel_extended_utils import set_extended_mode

# Configure both motors for Extended Position Mode
set_extended_mode(1)  # EQX motor
set_extended_mode(2)  # AoV motor

# Done! Motors will remember this setting.
```

### Every Boot Routine

```python
from dynamixel_extended_utils import orbigator_init, write_dword

# 1. Read current positions
lan_pos, aov_pos = orbigator_init()

# 2. Use these as your baseline for movements
# Example: Move EQX motor forward by 90° from current position
degrees_to_move = 90
ticks_per_degree = 4096 / 360.0
new_lan_pos = lan_pos + int(degrees_to_move * ticks_per_degree)

write_dword(1, 116, new_lan_pos)  # ADDR_GOAL_POSITION = 116
```

---

## 🚀 Orbigator Integration Example

```python
"""
Orbigator main control loop with Extended Position Mode
"""

from dynamixel_extended_utils import orbigator_init, write_dword
import time

# Initialize on boot
print("Initializing Orbigator motors...")
lan_position, aov_position = orbigator_init()

if lan_position is None or aov_position is None:
    print("ERROR: Failed to initialize motors!")
    exit()

# Orbital simulation parameters
TICKS_PER_DEGREE = 4096 / 360.0

def set_orbital_position(lan_degrees, aov_degrees):
    """
    Set orbital position in degrees.
    EQX: Equator crossing (orbital plane rotation)
    AoV: Argument of Vehicle (position along orbit)
    """
    global lan_position, aov_position
    
    # Calculate target positions
    lan_target = int(lan_degrees * TICKS_PER_DEGREE)
    aov_target = int(aov_degrees * TICKS_PER_DEGREE)
    
    # Send commands
    write_dword(1, 116, lan_target)
    write_dword(2, 116, aov_target)
    
    # Update tracking
    lan_position = lan_target
    aov_position = aov_target

# Example: Simulate one complete orbit
print("\nSimulating orbital motion...")
for aov_angle in range(0, 720, 1):  # Two complete orbits
    set_orbital_position(lan_degrees=45, aov_degrees=aov_angle)
    time.sleep(0.1)
    
    if aov_angle % 90 == 0:
        print(f"AoV: {aov_angle}° ({aov_angle/360:.1f} orbits)")

print("\n✓ Simulation complete!")
```

---

## 🔧 Troubleshooting

### Motor Jumps on Boot

**Problem:** Motor rapidly spins to unexpected position when powered on.

**Solution:** You forgot to read the present position before sending commands!

```python
# WRONG - Don't do this:
write_dword(1, 116, 0)  # Motor jumps to position 0!

# CORRECT - Do this:
current_pos = read_present_position(1)
write_dword(1, 116, current_pos)  # Motor stays in place
```

### Position Seems Wrong After Power Cycle

**Problem:** Position values don't match what you expect.

**Explanation:** Extended Position Mode maintains the cumulative position across power cycles. This is **correct behavior**.

**Solution:** Always read the present position on boot and use it as your baseline.

### Want to "Reset" Position Counter

**Problem:** Position values are very large after extended operation.

**Solution:** Use `clear_multi_turn()` command:

```python
from dynamixel_extended_utils import clear_multi_turn

clear_multi_turn(1)  # Resets position to 0-4095 range without moving
clear_multi_turn(2)
```

---

## 📚 Reference

### Key Functions

| Function | Purpose | When to Use |
|---|---|---|
| `set_extended_mode(id)` | Configure Mode 4 | One-time setup |
| `orbigator_init()` | Read positions on boot | Every boot |
| `read_present_position(id)` | Get current position | Anytime |
| `write_dword(id, 116, pos)` | Set goal position | Normal operation |
| `clear_multi_turn(id)` | Reset counter | Optional maintenance |

### Important Addresses

| Address | Name | Purpose |
|---|---|---|
| 11 | Operating Mode | Set to 4 for Extended Position |
| 64 | Torque Enable | 0=off, 1=on |
| 116 | Goal Position | Target position (32-bit) |
| 132 | Present Position | Current position (32-bit) |

---

## ✅ Summary Checklist for 2025

- [x] **Keep it in Mode 4:** Set once, leave permanently
- [x] **Ignore the Integer:** 62+ years to overflow at 1°/10sec
- [x] **Power-On Routine:** Read `Present Position` on every boot
- [x] **Use as Baseline:** Never assume position = 0 on boot
- [x] **Optional Reset:** Use `clear_multi_turn()` only if needed

---

**Your motors are now configured for continuous orbital tracking! 🛰️**

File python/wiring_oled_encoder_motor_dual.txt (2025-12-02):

Raspberry Pi Pico 2  (USB at top)
----------------------------------------------------
# OLED Display (I²C0)
GP4   -> OLED SDA
GP5   -> OLED SCL
3V3   -> OLED VCC
GND   -> OLED GND

# Encoder (quadrature + push)
GP6   -> Encoder A
GP7   -> Encoder B
GP8   -> Encoder SW (push button)
GND   -> Encoder CON (common)

# Stepper Motor Driver 1 (DRV8834 #1)
GP12  -> DRV8834 #1 nSLEEP   (HIGH = awake)
GP13  -> DRV8834 #1 nENBL    (LOW = enabled)
GP14  -> DRV8834 #1 STEP
GP15  -> DRV8834 #1 DIR
GND   -> DRV8834 #1 GND
VBUS  -> DRV8834 #1 VMOT (external motor supply)
       -> DRV8834 #1 A1/A2, B1/B2 -> Motor 1 coils

# Stepper Motor Driver 2 (DRV8834 #2)
GP16  -> DRV8834 #2 nSLEEP   (HIGH = awake)
GP17  -> DRV8834 #2 nENBL    (LOW = enabled)
GP18  -> DRV8834 #2 STEP
GP19  -> DRV8834 #2 DIR
GND   -> DRV8834 #2 GND
VBUS  -> DRV8834 #2 VMOT (external motor supply)
       -> DRV8834 #2 A1/A2, B1/B2 -> Motor 2 coils

Notes
Grounds: Tie Pico GND, both DRV8834 GNDs, and encoder GND together.
VMOT: Both drivers can share the same external motor supply (e.g. 5–10 V) if current capacity is
sufficient.
Independent control: Each motor has its own STEP/DIR/ENBL/SLEEP. You can run them in parallel or
sequence in software.
Expansion: GP10/GP11 are still free if you want runtime microstep mode control (M0/M1).

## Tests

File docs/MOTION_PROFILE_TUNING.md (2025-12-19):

# Motion Profile Tuning Guide

## Overview

The DYNAMIXEL motors support smooth motion profiles that eliminate jerky movement. This is controlled by two parameters:

- **Profile Velocity**: Controls maximum speed during movement
- **Profile Acceleration**: Controls how quickly the motor accelerates/decelerates

## Default Settings

The motors are initialized with these default values:
```python
velocity = 50       # Moderate speed limit
acceleration = 20   # Smooth acceleration
```

## Tuning Guidelines

### For Smoother Motion (Less Jerky)
- **Increase** Profile Acceleration (e.g., 30-50)
  - Higher values = slower, gentler acceleration
  - Makes starts and stops very smooth
  
- **Increase** Profile Velocity (e.g., 70-100)
  - Higher values = slower maximum speed
  - Reduces abrupt movements

### For Faster Response (More Responsive)
- **Decrease** Profile Acceleration (e.g., 5-15)
  - Lower values = quicker acceleration
  - Motor responds faster to commands
  
- **Decrease** Profile Velocity (e.g., 20-40)
  - Lower values = higher maximum speed
  - Faster movements

### For Maximum Speed (No Smoothing)
```python
velocity = 0        # No speed limit
acceleration = 0    # No acceleration limit
```
**Warning**: This will make motion very jerky!

## How to Adjust

### Method 1: Change Default in Code

Edit `dynamixel_motor.py`, line ~57:
```python
self.set_motion_profile(velocity=50, acceleration=20)
```

Change the values to your preference.

### Method 2: Adjust After Initialization

In `orbigator.py`, after motor initialization:
```python
# Make AoV motor extra smooth
aov_motor.set_motion_profile(velocity=80, acceleration=40)

# Make EQX motor more responsive
eqx_motor.set_motion_profile(velocity=30, acceleration=15)
```

### Method 3: Dynamic Adjustment

Add to your main loop or state machine:
```python
# Smooth mode for precise positioning
if current_state in [1, 2]:  # Setup states
    aov_motor.set_motion_profile(velocity=80, acceleration=40)

# Faster mode for running simulation
elif current_state == 3:  # Running state
    aov_motor.set_motion_profile(velocity=40, acceleration=20)
```

## Recommended Profiles

### For AoV Motor (Pointer Arm)
```python
# Extra smooth (recommended for visible pointer)
aov_motor.set_motion_profile(velocity=60, acceleration=30)
```

### For EQX Motor (Orbital Plane)
```python
# Moderate smooth (slower movements anyway due to gearing)
eqx_motor.set_motion_profile(velocity=40, acceleration=20)
```

## Value Ranges

- **Valid range**: 0 to 32767
- **Practical range**: 0 to 200
- **Recommended range**: 10 to 100

## Testing

To test different profiles:
1. Upload modified code to Pico
2. Watch the motor movement during encoder adjustments
3. Adjust values up or down based on feel
4. Repeat until motion feels smooth and responsive

## Notes

- Profile settings are stored in RAM, not EEPROM
- Settings reset on power cycle
- Each motor can have different profiles
- Changes take effect immediately on next movement command

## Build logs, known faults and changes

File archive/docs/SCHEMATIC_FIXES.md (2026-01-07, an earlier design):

# Required Schematic Fixes

Based on review of `kicad/orbigator.net` vs `ORBIGATOR_CIRCUIT_DIAGRAM.txt` (updated).

## 1. Buffer Pull-Up Voltage Logic (CONFIRMED)
User has tested and confirmed that the Data Bus pull-up (R1) should be to **3.3V**, not 5V.
- **Old Schematic**: R1 connected to +5V.
- **Action**: Connect `R1` (10kΩ) to **+3.3V** rail instead of +5V.
    - This protects the 3.3V-powered buffer (74HC126) from seeing 5V on its output/feedback path.
    - **Verify**: R1 should connect `DATA_BUS` to `+3V3`.

## 2. Review I2C Pull-ups
- Schematic seems correct (R2, R3 to 3.3V). Just re-confirm.

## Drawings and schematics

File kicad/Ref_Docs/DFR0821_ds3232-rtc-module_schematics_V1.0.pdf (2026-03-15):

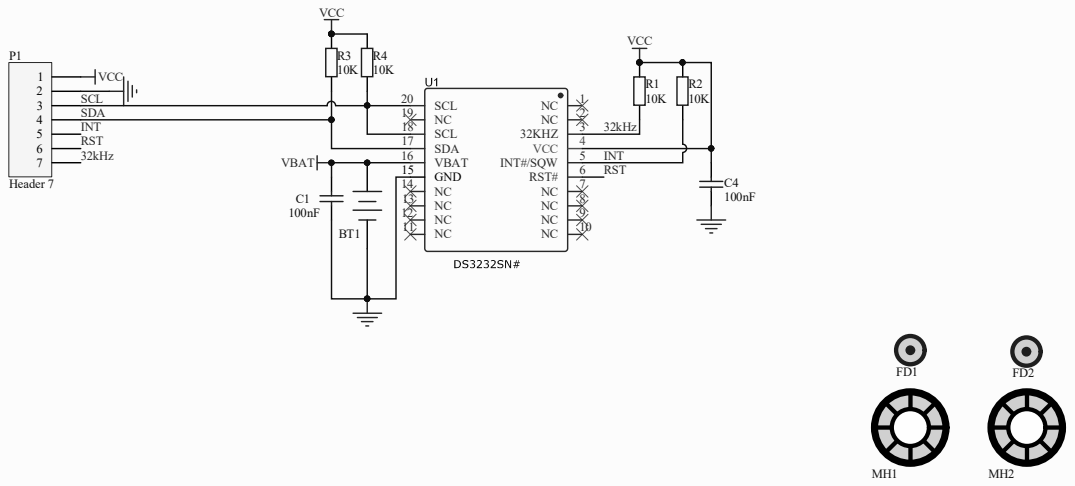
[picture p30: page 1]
DS3232 Precise RTC Breakout Board; DFR0821 HDJ-CD; Title: Drawn: Page:; Code: Size:; Date:; Time:; Revision:; R3 SDA; SCLVCC; INT; BT1 VCC; VCC; 32kHz; INT RST; 32kHz RST; 7 P1Header 7; VBAT; 32KHZ; 3 VCC; INT#/SQW; 5 RST#; GND 15; VBAT 16; SDA 17; SCL 18; SCL 20

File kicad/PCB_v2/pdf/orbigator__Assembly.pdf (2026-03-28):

1 | 2 | 3 | 4 | 5 | 6

AB

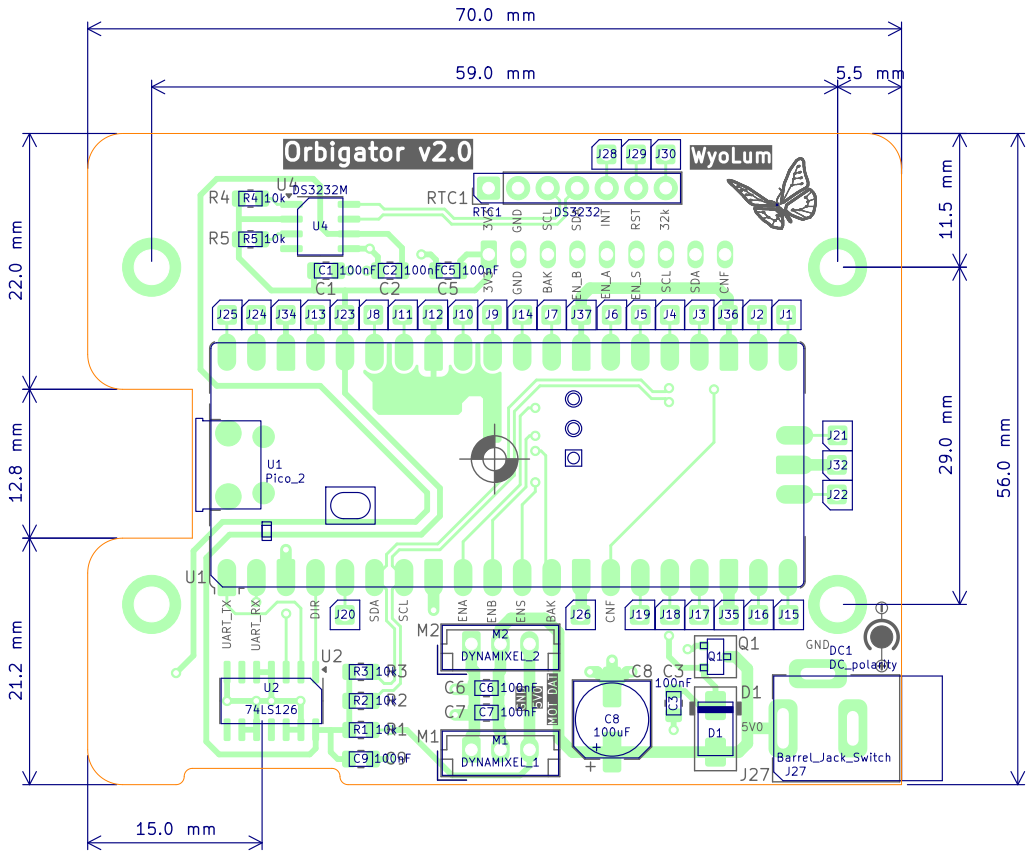
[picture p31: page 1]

BT1 DISP1 1 | 2 | 3 | 4 | 5 | 6

AB

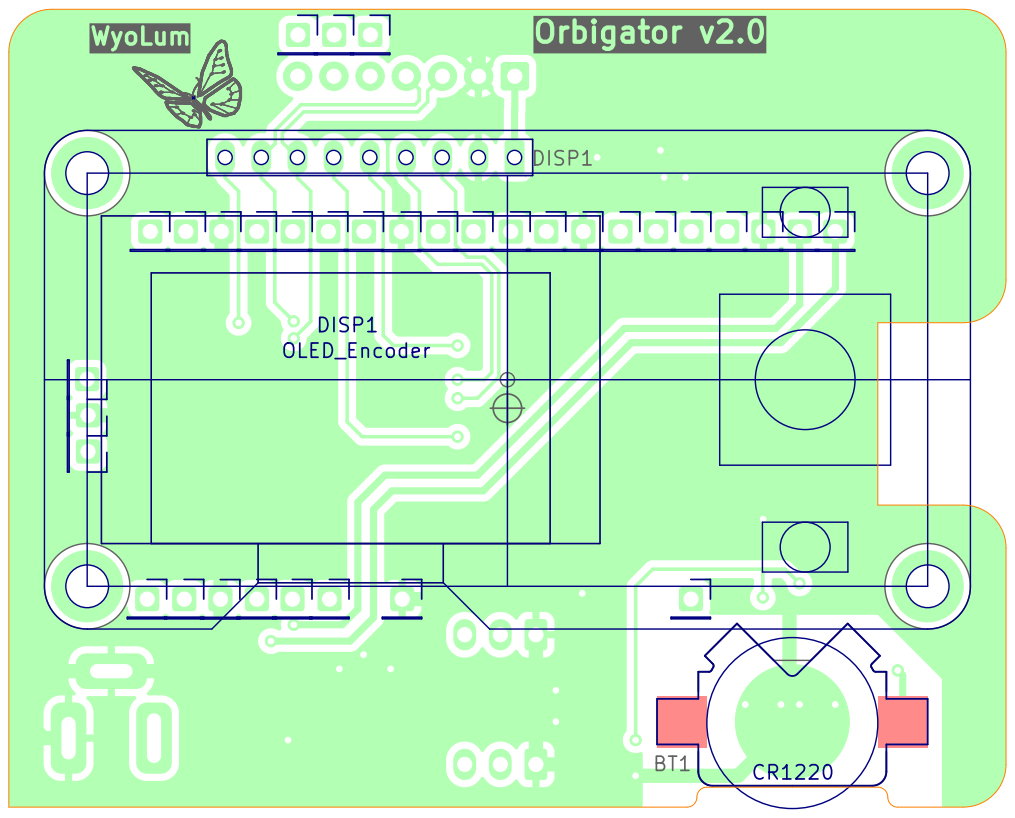
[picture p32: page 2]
D Date: 2026⁻01⁻31 KiCad E.D.A. 10.0.0; Size: A4; Rev: v2; Title: Orbigator; File: orbigator.kicad_pcb; Sheet:; WyoLum; CR1220 OLED_Encoder DISP1

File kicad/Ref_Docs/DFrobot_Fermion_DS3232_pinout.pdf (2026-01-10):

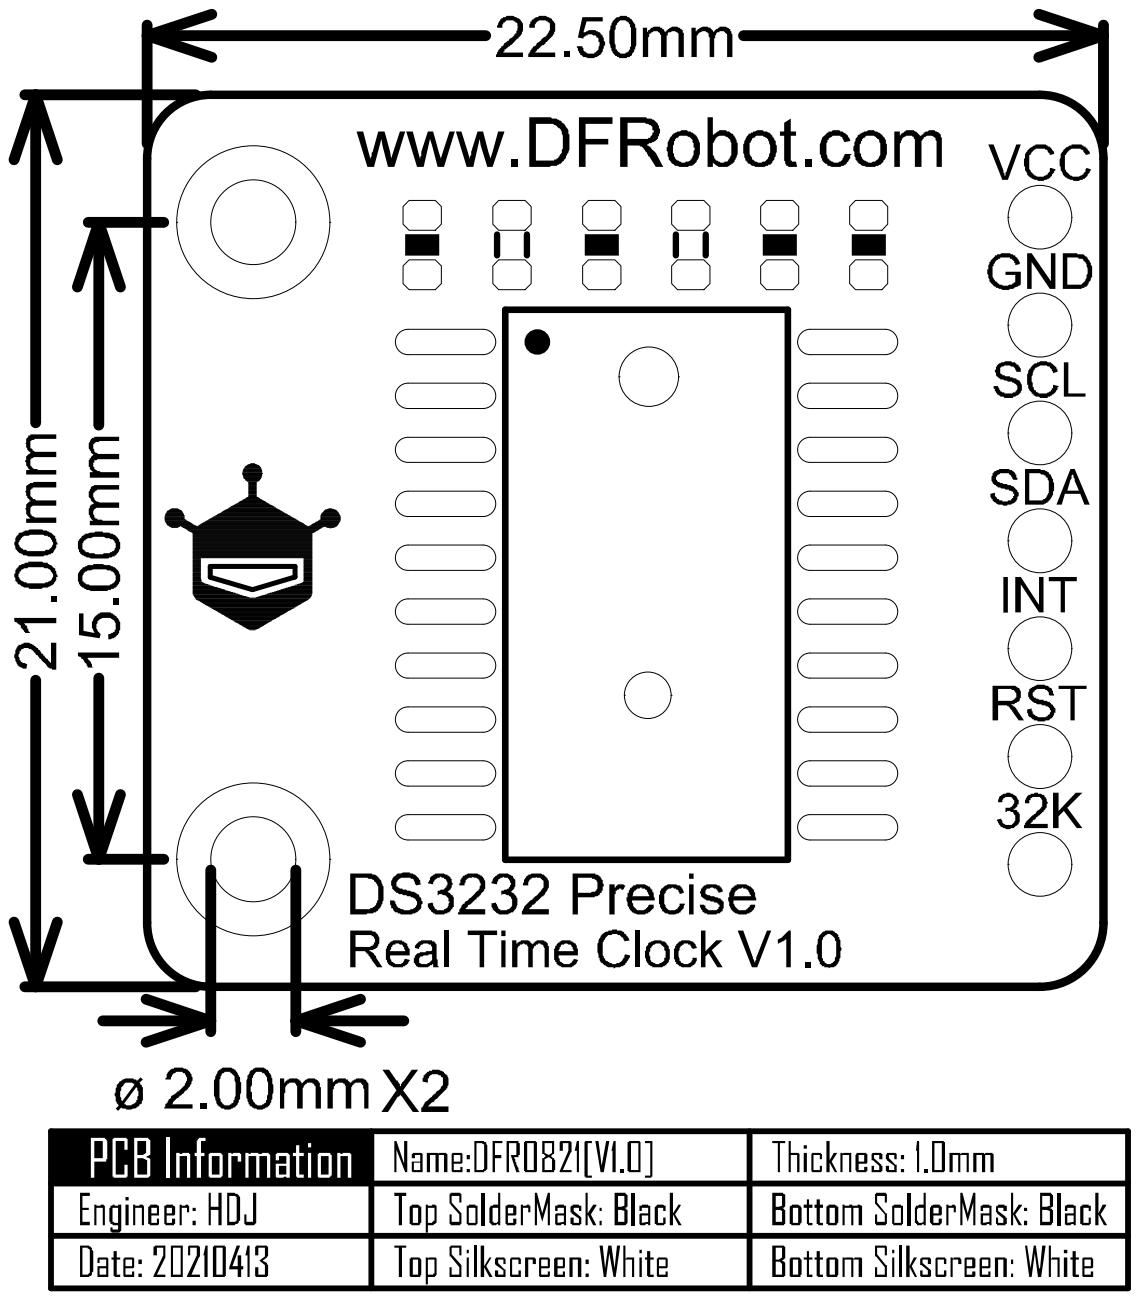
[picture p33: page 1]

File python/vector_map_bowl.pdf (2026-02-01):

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

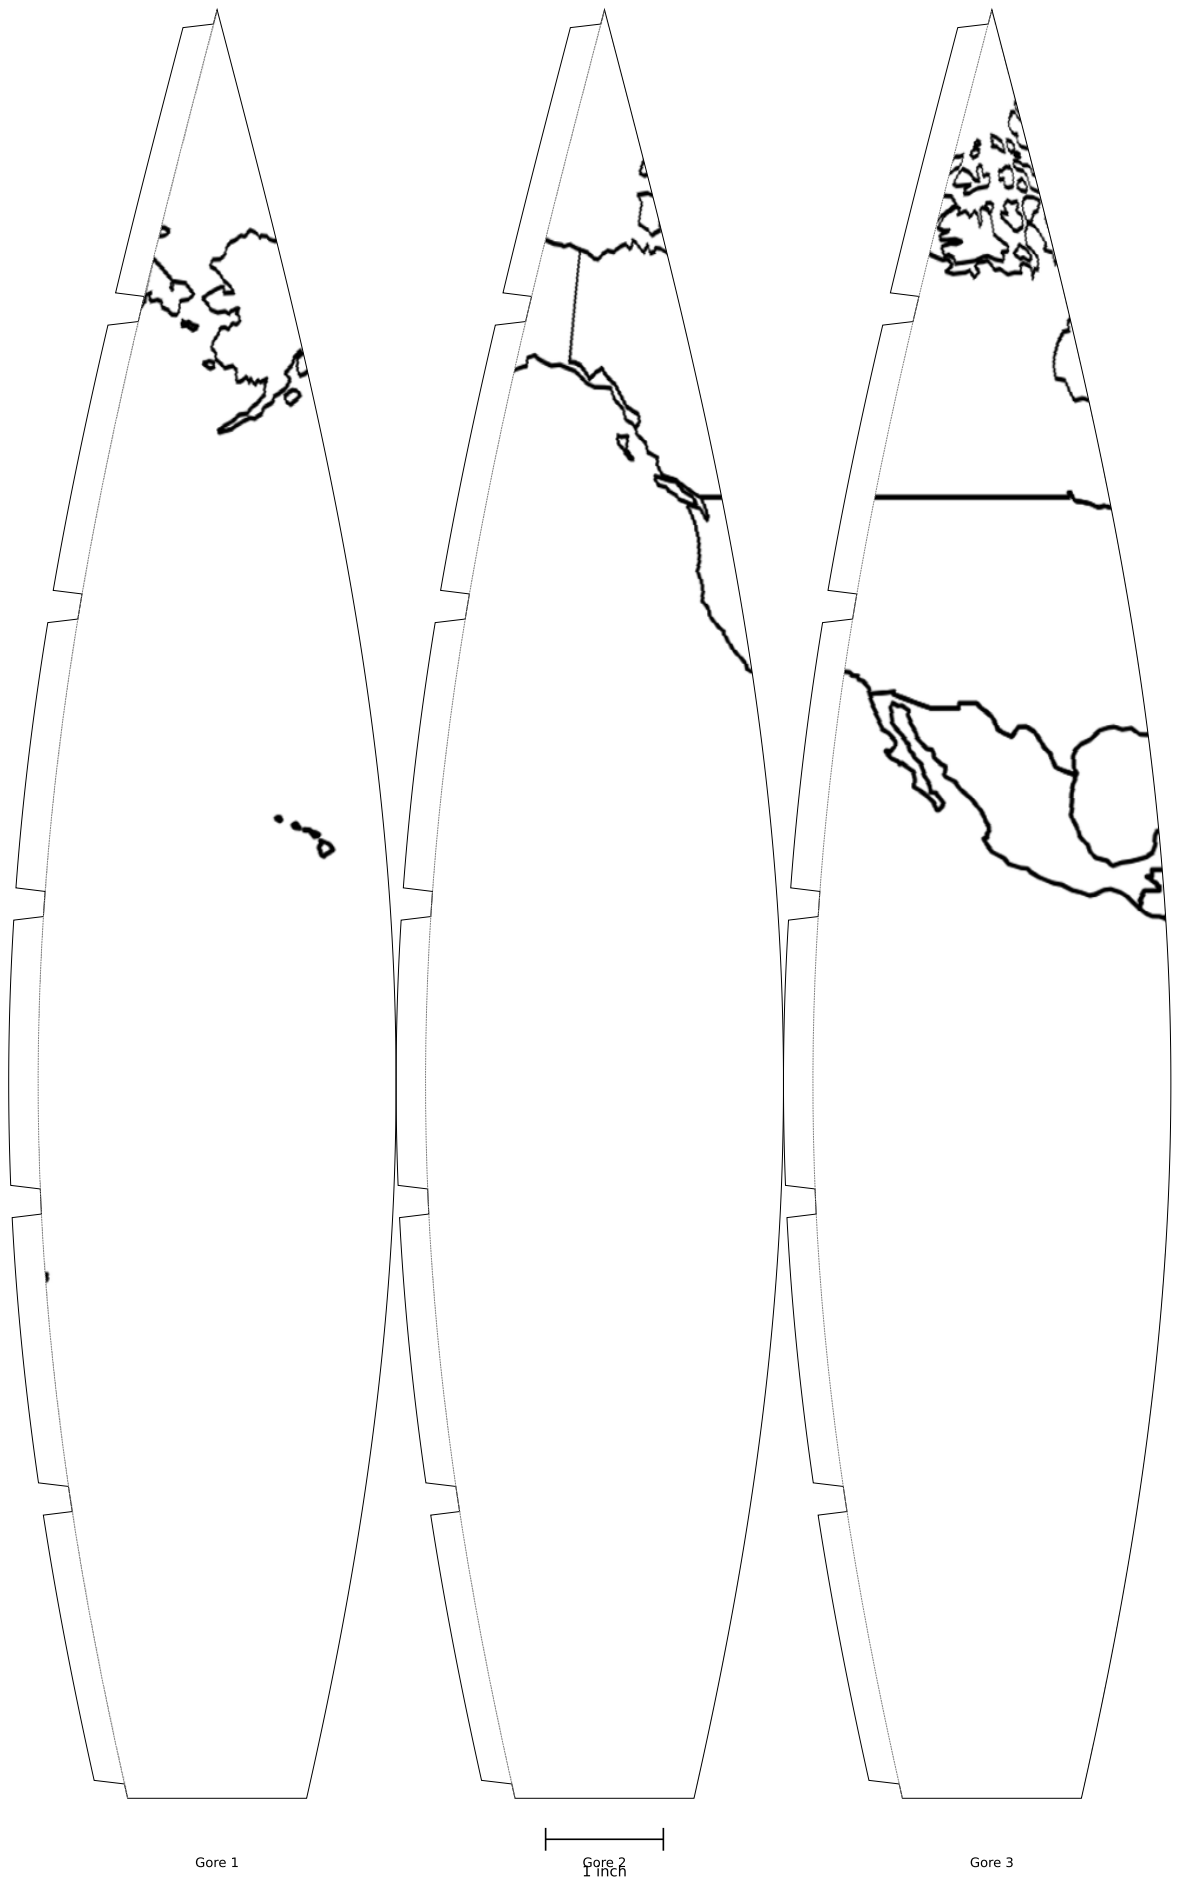
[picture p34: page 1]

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

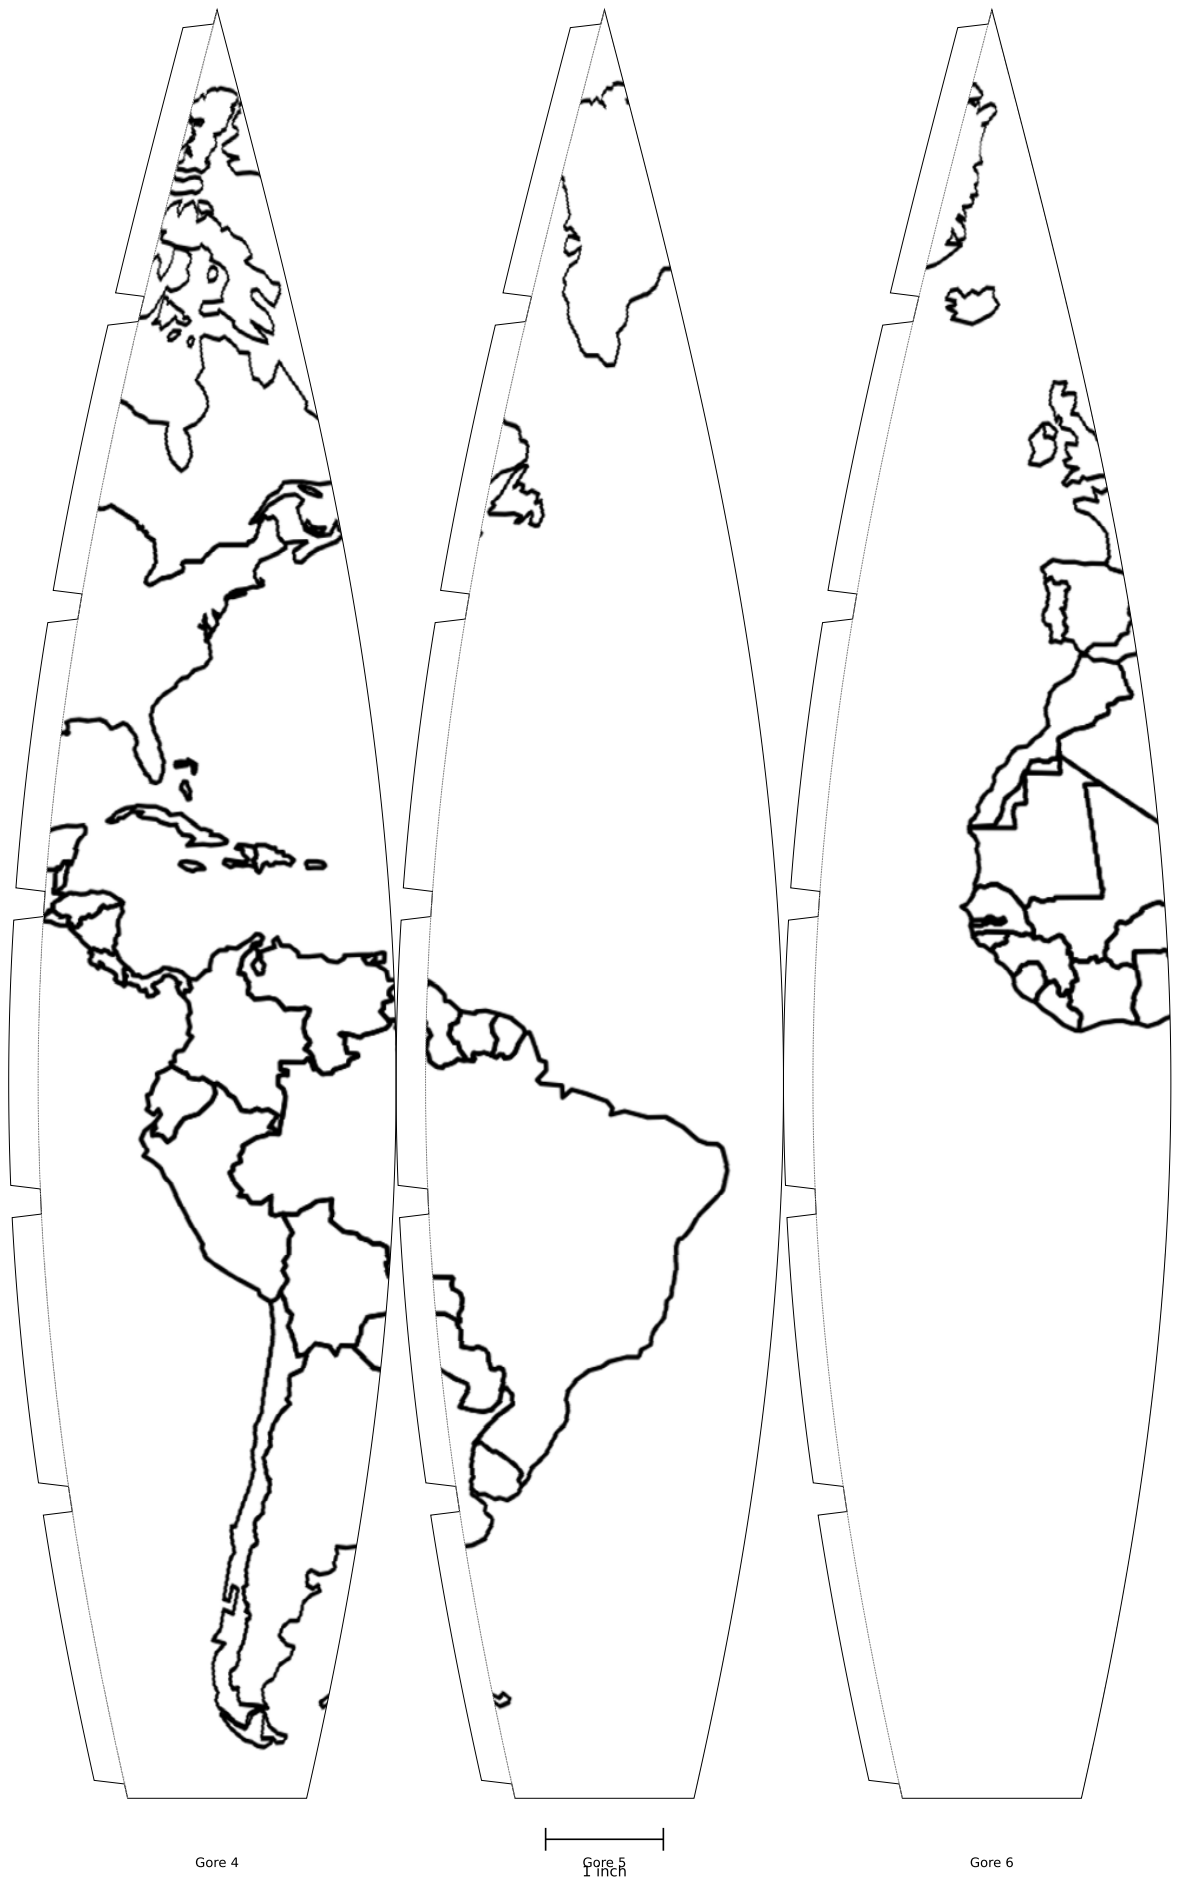
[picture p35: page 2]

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

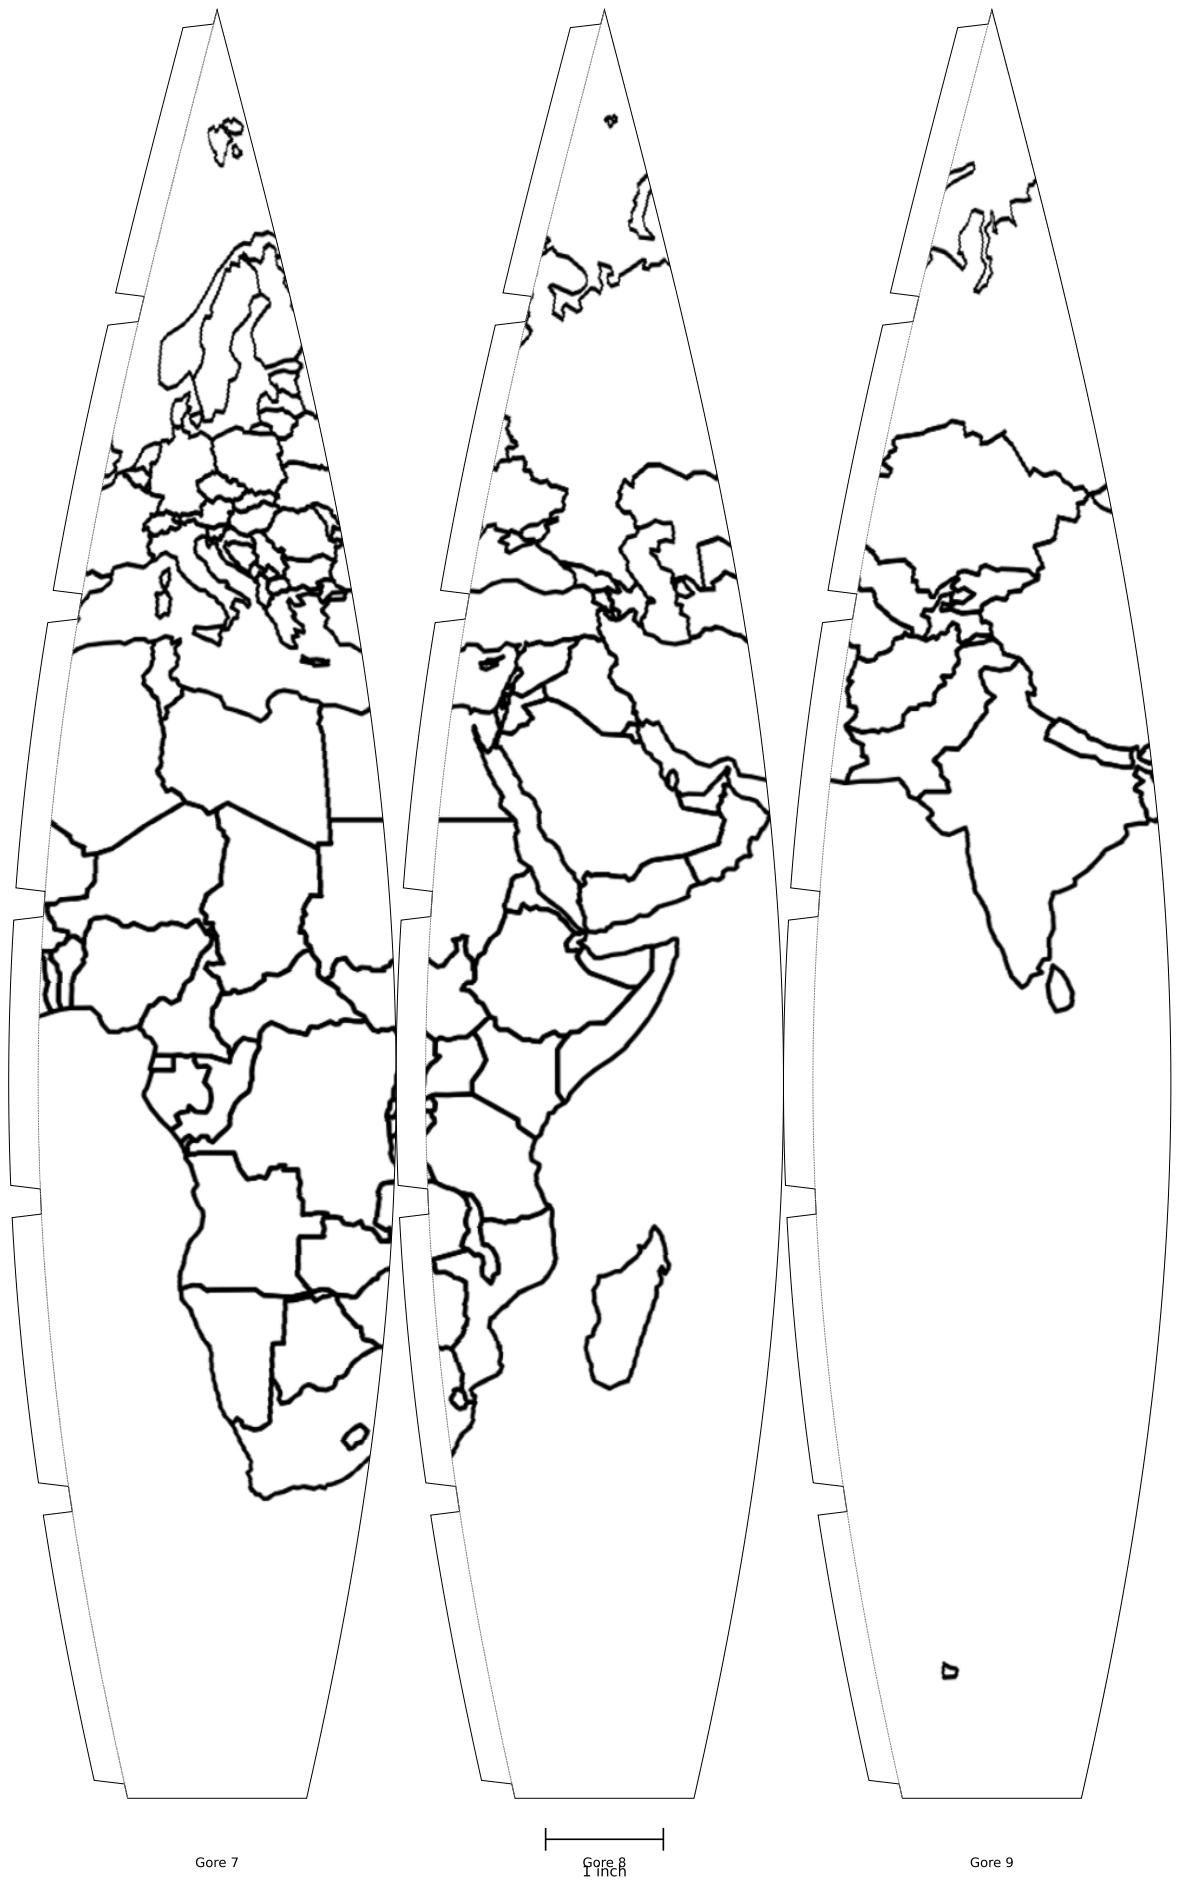
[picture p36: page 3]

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

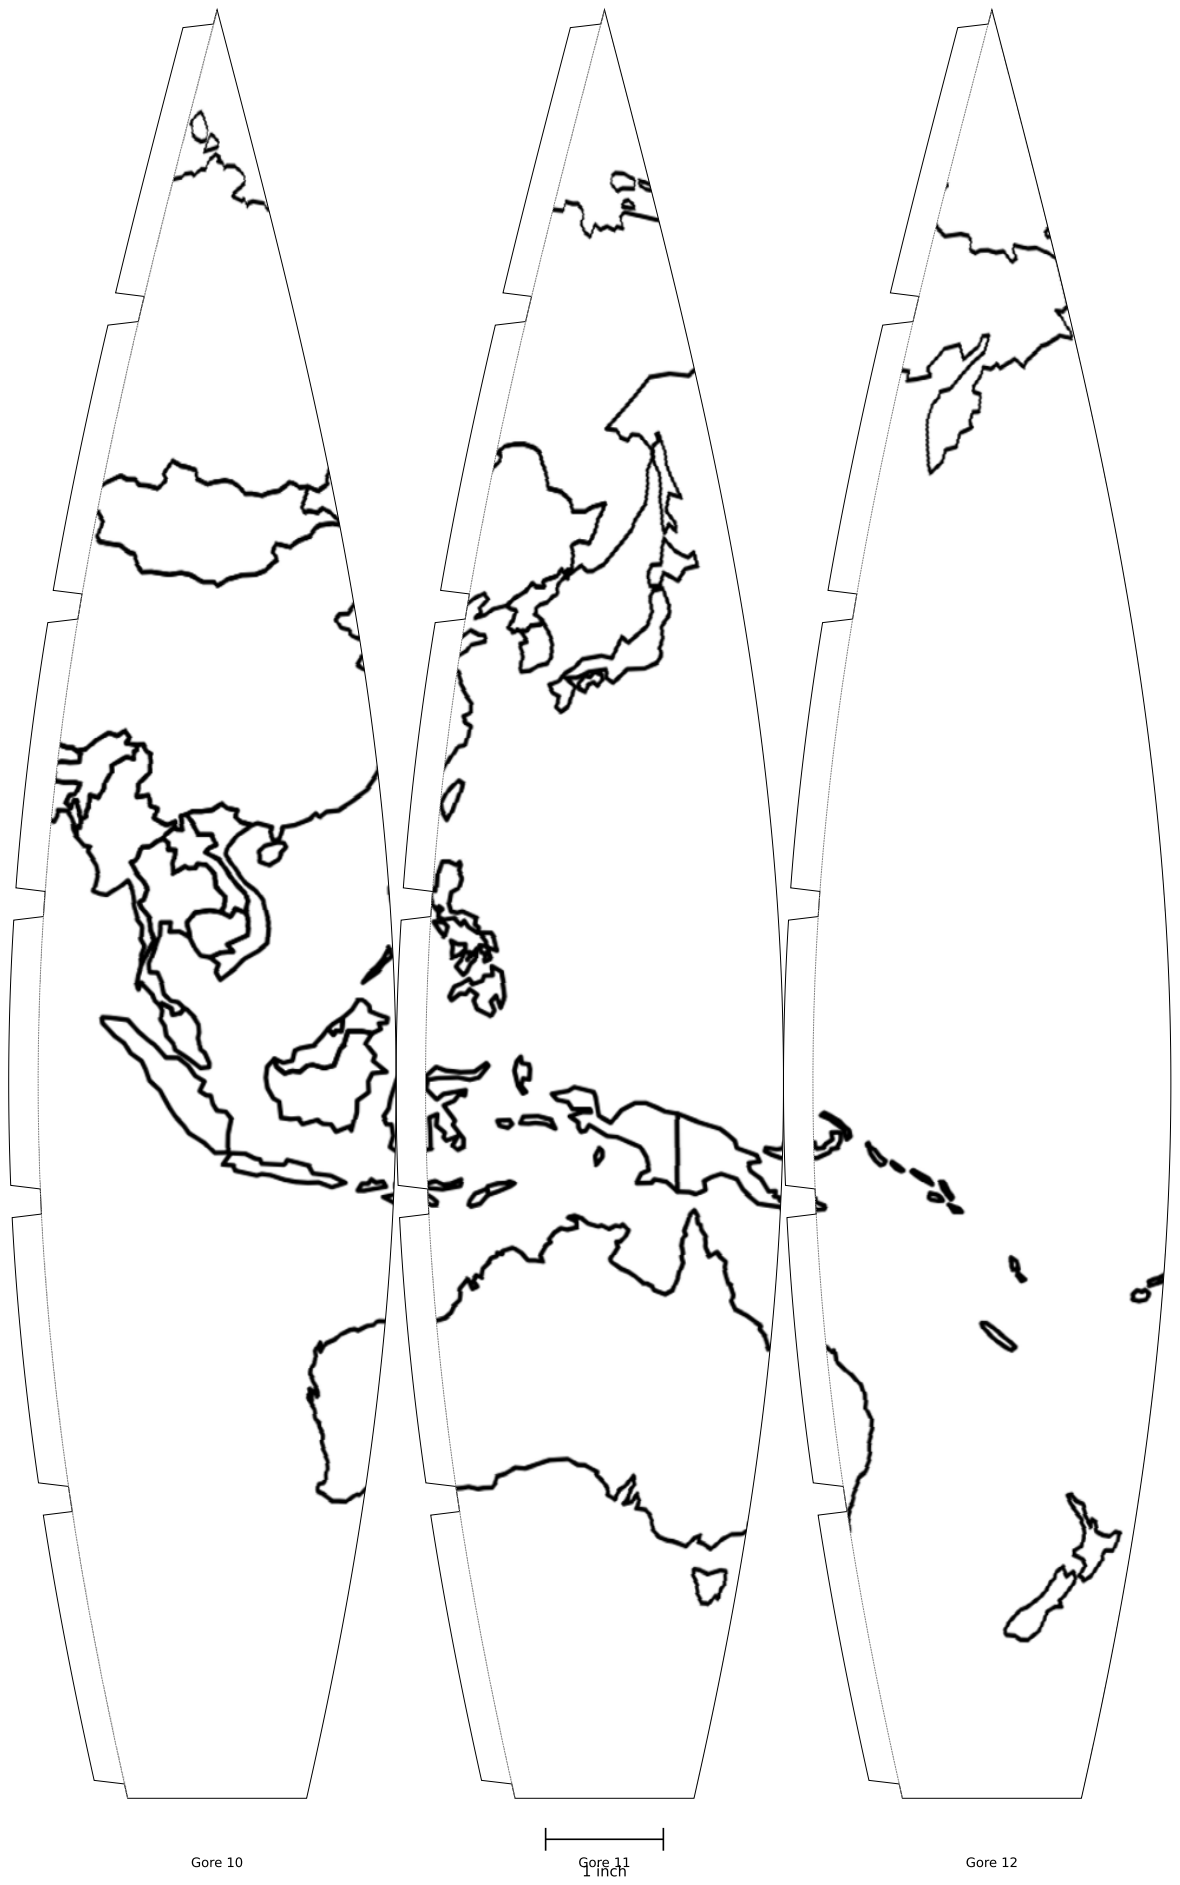
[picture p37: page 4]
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

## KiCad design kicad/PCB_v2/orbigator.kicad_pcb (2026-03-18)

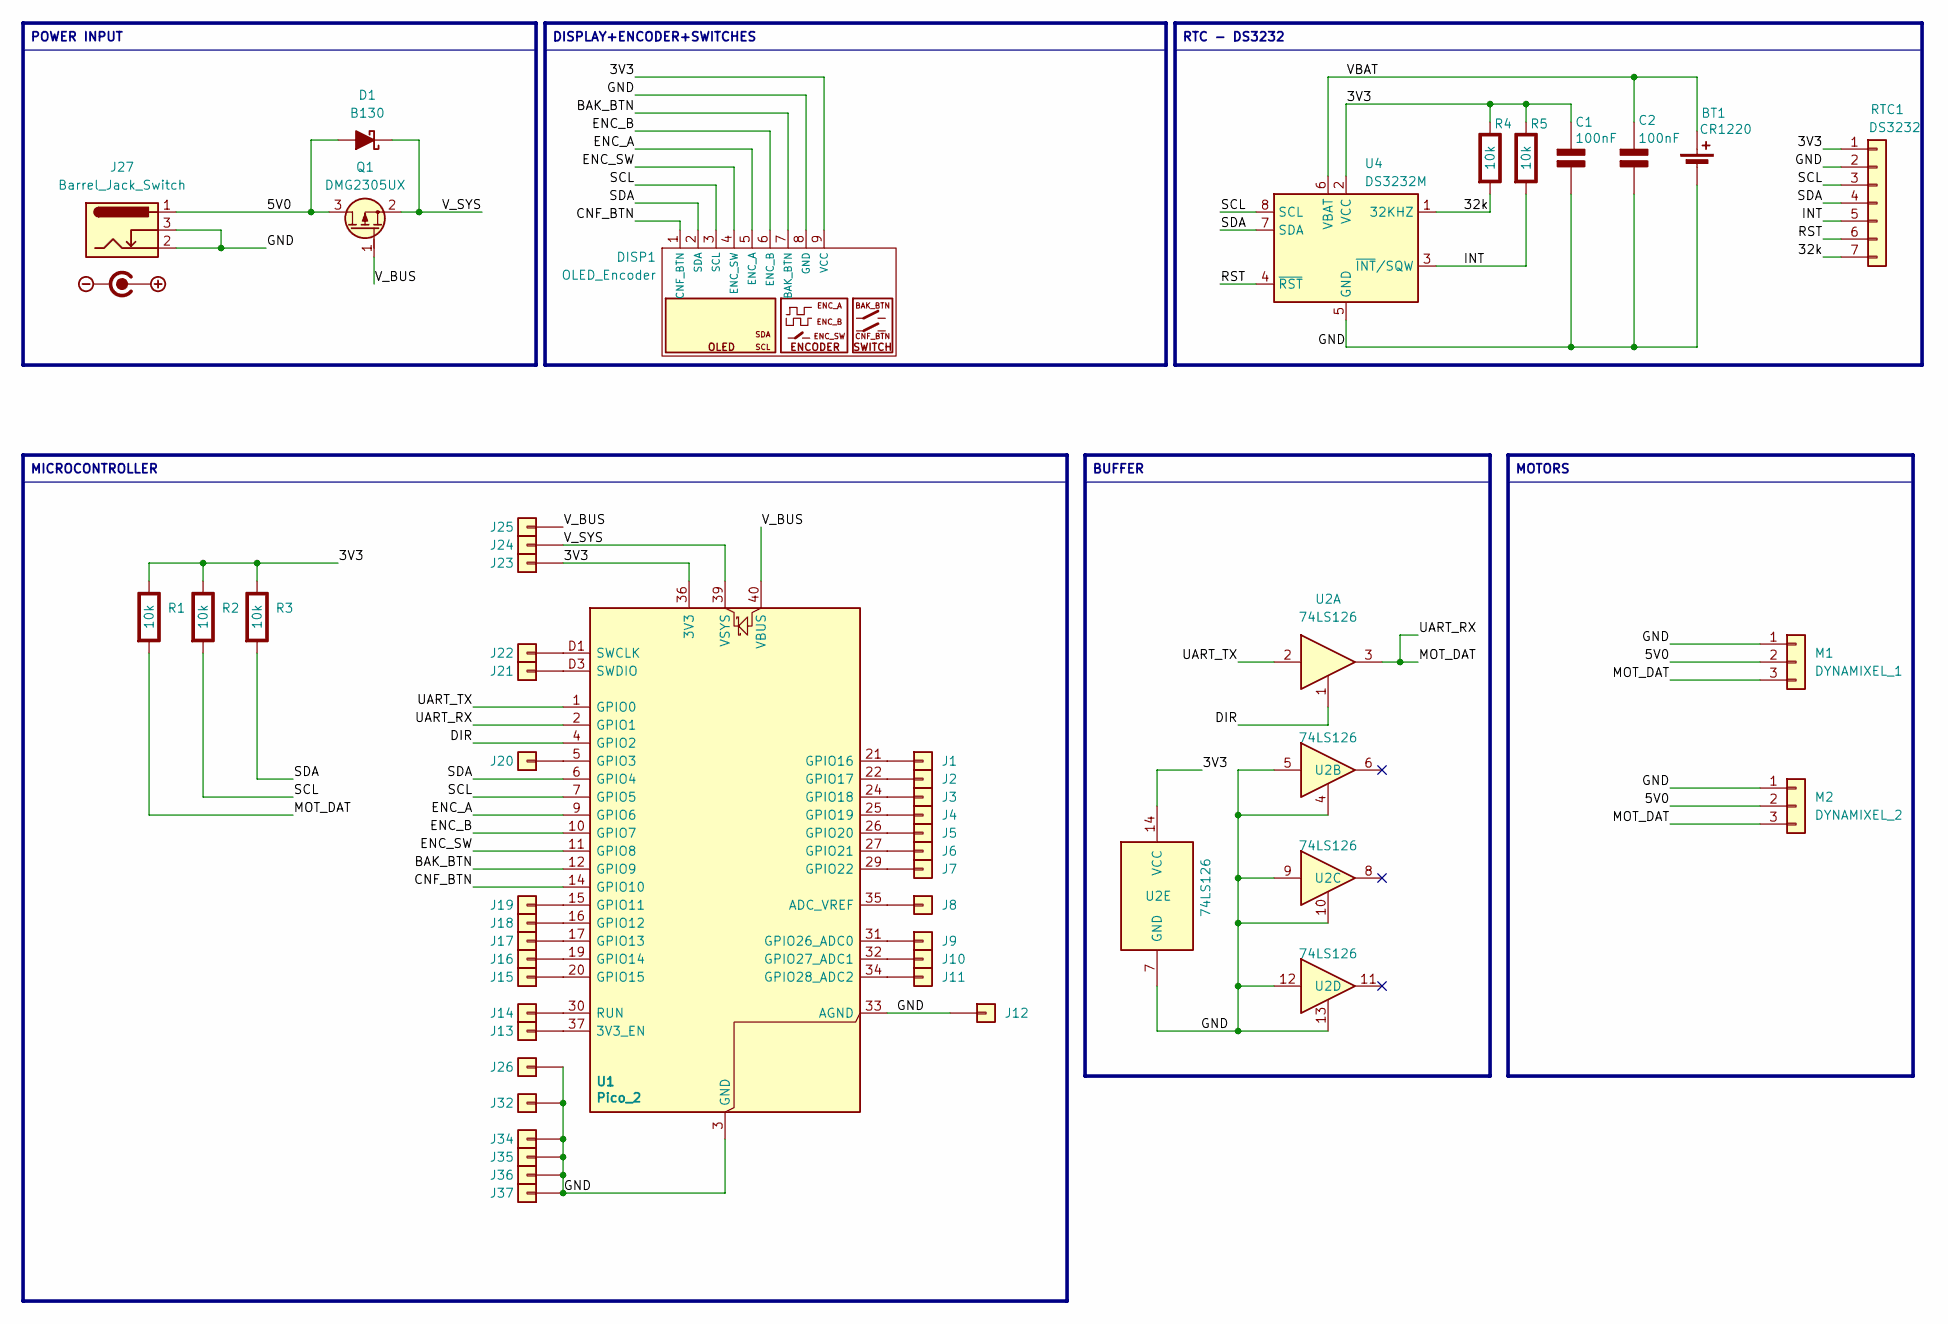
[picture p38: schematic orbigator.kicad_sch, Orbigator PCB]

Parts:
BT1: CR1220; BatteryHolder_LINX_BAT-HLD-012-SMT
C1, C2: 100nF; C_0805_2012Metric_Pad1.18x1.45mm_HandSolder; Rating V
D1: B130; D_SMA
DISP1: OLED_Encoder; OLED_ENC3
J1, J2, J3, J4, J5, J6, J7, J8, J9, J10, J11, J12, J13, J14, J15, J16, J17, J18, J19, J20, J21, J22, J23, J24, J25, J26, J32, J34, J35, J36, J37: Conn_01x01; PinHeader_1x01_P2.54mm_Vertical
J27: Barrel_Jack_Switch; BarrelJack_Horizontal
M1: DYNAMIXEL_1; JST_EH_B3B-EH-A_1x03_P2.50mm_Vertical
M2: DYNAMIXEL_2; JST_EH_B3B-EH-A_1x03_P2.50mm_Vertical
Q1: DMG2305UX; SOT-23
R1, R2, R3, R4, R5: 10k; R_0805_2012Metric_Pad1.20x1.40mm_HandSolder; Rating W
RTC1: DS3232; DS3232_RTC_vert
U1: Pico_2; RaspberryPi_Pico_SMD_HandSolder
U2: 74LS126; SOIC-14_3.9x8.7mm_P1.27mm
U3: DC_polarity; DC
U4: DS3232M; SOIC-8_3.9x4.9mm_P1.27mm

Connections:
/3V3: C1.1 (+), DISP1.9 (VCC), J23.1, R1.1 (+), R2.1 (+), R3.1 (+), R4.1 (+), R5.1 (+), RTC1.1, U1.36 (3V3), U2.14 (VCC), U4.2 (VCC)
/5V0: D1.2 (A), J27.1, M1.2, M2.2, Q1.3 (D)
/32k: R4.2 (-), RTC1.7, U4.1 (32KHZ)
/BAK_BTN: DISP1.7 (BAK_BTN), U1.12 (GPIO9)
/CNF_BTN: DISP1.1 (CNF_BTN), U1.14 (GPIO10)
/DIR: U1.4 (GPIO2), U2.1
/ENC_A: DISP1.5 (ENC_A), U1.9 (GPIO6)
/ENC_B: DISP1.6 (ENC_B), U1.10 (GPIO7)
/ENC_SW: DISP1.4 (ENC_SW), U1.11 (GPIO8)
/GND: BT1.2 (-), C1.2 (-), C2.2 (-), DISP1.8 (GND), J12.1, J26.1, J27.2, J27.3, J32.1, J34.1, J35.1, J36.1, J37.1, M1.1, M2.1, RTC1.2, U1.3 (GND), U1.8 (GND), U1.13 (GND), U1.18 (GND), U1.23 (GND), U1.28 (GND), U1.33 (AGND), U1.38 (GND), U1.D2 (GND), U2.4, U2.5, U2.7 (GND), U2.9, U2.10, U2.12, U2.13, U4.5 (GND)
/INT: R5.2 (-), RTC1.5, U4.3 (~INT/SQW)
/MOT_DAT: M1.3, M2.3, R1.2 (-), U1.2 (GPIO1), U2.3
/RST: RTC1.6, U4.4 (~RST)
/SCL: DISP1.3 (SCL), R2.2 (-), RTC1.3, U1.7 (GPIO5), U4.8 (SCL)
/SDA: DISP1.2 (SDA), R3.2 (-), RTC1.4, U1.6 (GPIO4), U4.7 (SDA)
/UART_TX: U1.1 (GPIO0), U2.2
/VBAT: BT1.1 (+), C2.1 (+), U4.6 (VBAT)
/V_BUS: J25.1, Q1.1 (G), U1.40 (VBUS)
/V_SYS: D1.1 (K), J24.1, Q1.2 (S), U1.39 (VSYS)
unnamed: J1.1, U1.21 (GPIO16)
unnamed: J2.1, U1.22 (GPIO17)
unnamed: J3.1, U1.24 (GPIO18)
unnamed: J4.1, U1.25 (GPIO19)
unnamed: J5.1, U1.26 (GPIO20)
unnamed: J6.1, U1.27 (GPIO21)
unnamed: J7.1, U1.29 (GPIO22)
unnamed: J8.1, U1.35 (ADC_VREF)
unnamed: J9.1, U1.31 (GPIO26_ADC0)
unnamed: J10.1, U1.32 (GPIO27_ADC1)
unnamed: J11.1, U1.34 (GPIO28_ADC2)
unnamed: J13.1, U1.37 (3V3_EN)
unnamed: J14.1, U1.30 (RUN)
unnamed: J15.1, U1.20 (GPIO15)
unnamed: J16.1, U1.19 (GPIO14)
unnamed: J17.1, U1.17 (GPIO13)
unnamed: J18.1, U1.16 (GPIO12)
unnamed: J19.1, U1.15 (GPIO11)
unnamed: J20.1, U1.5 (GPIO3)
unnamed: J21.1, U1.D3 (SWDIO)
unnamed: J22.1, U1.D1 (SWCLK)

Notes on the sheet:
DISPLAY+ENCODER+SWITCHES
POWER INPUT
MOTORS
RTC - DS3232
BUFFER
MICROCONTROLLER

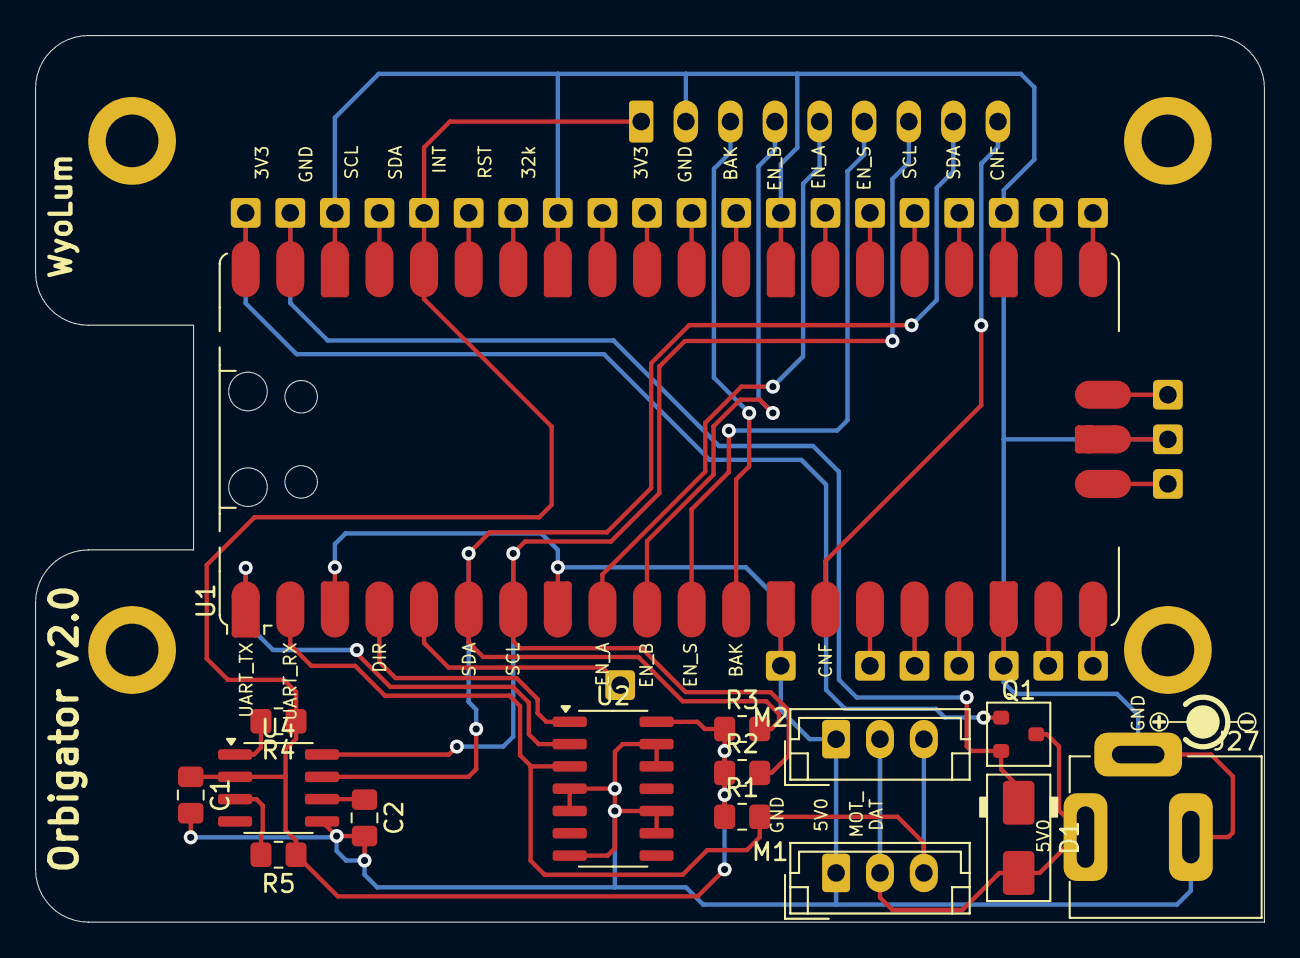
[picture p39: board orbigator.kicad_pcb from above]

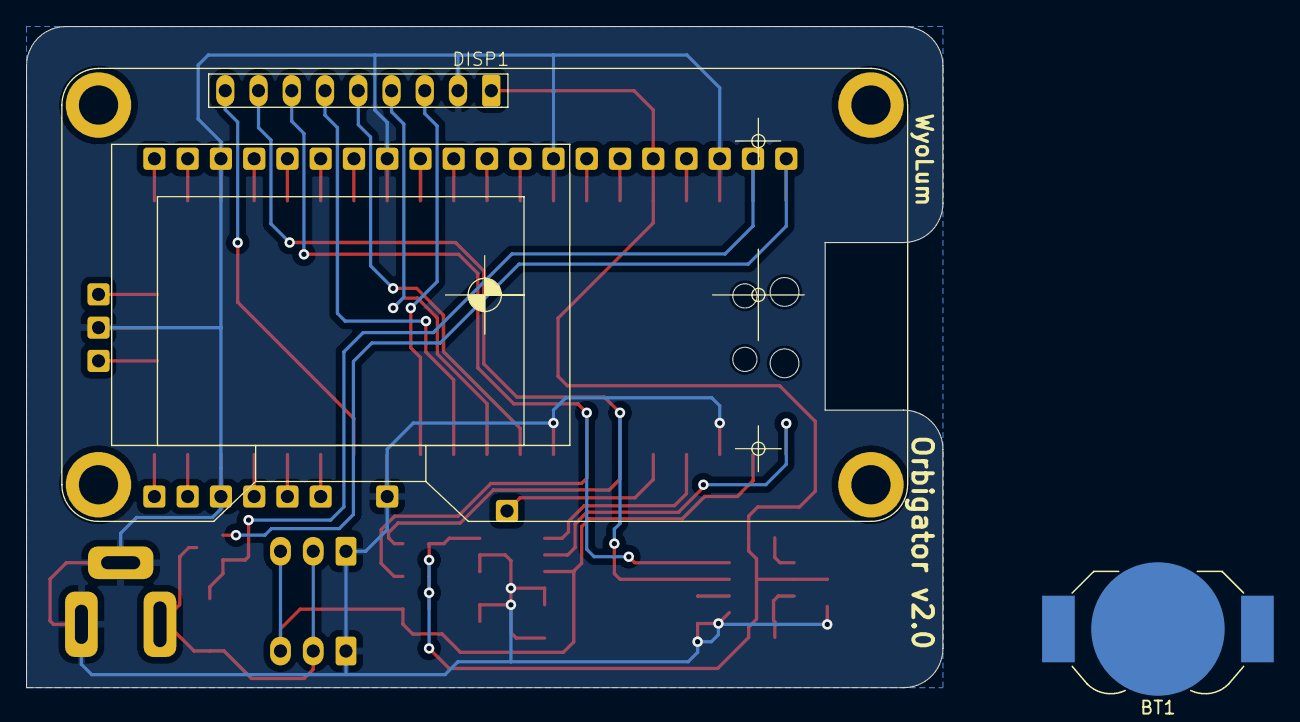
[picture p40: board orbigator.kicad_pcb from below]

Board: 2 copper layers, 70.0 x 50.5 mm, 49 parts (2 on the bottom side), 39 nets.

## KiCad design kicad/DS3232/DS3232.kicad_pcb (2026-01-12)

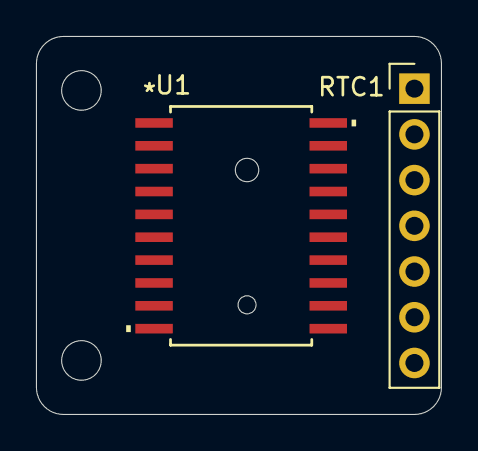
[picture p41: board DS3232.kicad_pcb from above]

Board: 2 copper layers, 22.5 x 21.0 mm, 5 parts (1 on the bottom side), 7 nets, no tracks yet.

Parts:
BT1: CR1220; BAT_1056
H1, H2: MountingHole; MountingHole_2.2mm_M2
RTC1: DS3232; PinHeader_1x07_P2.54mm_Vertical
U1: ds3232sn-; 21-0042B_20_MXM-M

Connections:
/3V3: RTC1.1, U1.4 (VCC)
/32k: RTC1.7, U1.3 (32KHZ)
/GND: RTC1.2, U1.15 (GND)
/INT: RTC1.5, U1.5 (*INT/SQW)
/RST: RTC1.6, U1.6 (*RST)
/SCL: RTC1.3, U1.18 (SCL), U1.20 (SCL)
/SDA: RTC1.4, U1.17 (SDA)

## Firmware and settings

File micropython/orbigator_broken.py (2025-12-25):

# Orbigator - Orbital Mechanics Simulator
# Pico 2 | DYNAMIXEL XL330-M288-T motors with orbital parameter computation
# EQX Motor (ID 1): Connected via 11T drive gear to 120T ring gear on globe
# AoV Motor (ID 2): Direct drive
# DYNAMIXEL: UART0 TX=GP0, RX=GP1, DIR=GP2 (via 74HC126 buffer)
# Encoder: A=GP6, B=GP7, SW=GP8 (pull-ups)
# Buttons: Back=GP9, Confirm=GP10 (pull-ups)
# OLED (SH1106/SSD1306 auto): I2C0 SDA=GP4, SCL=GP5

import machine, time, math, json
from machine import Pin, I2C
import framebuf
from ds3231 import DS3231
from dynamixel_motor import DynamixelMotor
from modes import MenuMode, OrbitMode

# ---------------- Constants ----------------
CONFIG_FILE = "orbigator_config.json"

# Earth parameters
EARTH_RADIUS = 6378.137  # km
EARTH_MU = 398600.4418   # km^3/s^2 (gravitational parameter)
EARTH_J2 = 0.00108263    # J2 perturbation coefficient
SIDEREAL_DAY_SEC = 86164.0905  # seconds (23.934 hours)
EARTH_ROTATION_DEG_DAY = 360.0  # Earth rotates 360° per sidereal day

# Motor IDs
AOV_MOTOR_ID = 2  # Argument of Vehicle (direct drive)
EQX_MOTOR_ID = 1  # Equator crossing (geared)

# Motor gear ratios
EQX_GEAR_RATIO = 120.0 / 11.0  # Ring gear / Drive gear (TBR: verify tooth count)
AOV_GEAR_RATIO = 1.0  # Direct drive

# Encoder settings
DETENT_DIV = 4   # Changed from 4 - makes encoder more responsive
DEBOUNCE_MS = 200

# Altitude range: 200 km to 2000 km
MIN_ALTITUDE_KM = 200
MAX_ALTITUDE_KM = 2000

MAX_AOV_SPEED = 10
MAX_EQX_SPEED = 50 ## unlimited

# ---------------- OLED init ----------------
OLED_W, OLED_H = 128, 64
# Using 100kHz for better reliability with ChronoDot/DS3231
i2c = I2C(0, sda=Pin(4), scl=Pin(5), freq=100_000)
addrs = i2c.scan()
if not addrs:
    print("No I2C devices found on I2C0 (GP4/GP5).")
    # Don't exit, might be loose connection, try to proceed
else:
    ADDR = addrs[0]

class SH1106_I2C:
    def __init__(self, w,h,i2c,addr=0x3C):
        self.width,self.height,self.i2c,self.addr = w,h,i2c,addr
        self.buffer = bytearray(w*h//8)
        self.fb = framebuf.FrameBuffer(self.buffer, w, h, framebuf.MONO_VLSB)
        def cmd(*cs):
            for c in cs: self.i2c.writeto(self.addr, b'\x00'+bytes([c]))
        cmd(0xAE,0x20,0x00,0x40,0xA1,0xC8,0x81,0x7F,0xA6,0xA8,0x3F,
            0xAD,0x8B,0xD3,0x00,0xD5,0x80,0xD9,0x22,0xDA,0x12,0xDB,0x35,0xAF)
        self.fill(0); self.show()
    def fill(self,c): self.fb.fill(c)
    def text(self,s,x,y,c=1): self.fb.text(s,x,y,c)
    def show(self):
        for p in range(self.height//8):
            self.i2c.writeto(self.addr, b'\x00'+bytes([0xB0+p,0x02,0x10]))
            s = self.width*p; e = s+self.width
            self.i2c.writeto(self.addr, b'\x40'+self.buffer[s:e])

try:
    if addrs:
        disp = SH1106_I2C(OLED_W, OLED_H, i2c, addr=ADDR); DRIVER="SH1106"
    else:
        raise Exception("No display")
except Exception:
    try:
        if addrs:
            from ssd1306 import SSD1306_I2C
            disp = SSD1306_I2C(OLED_W, OLED_H, i2c, addr=ADDR); DRIVER="SSD1306"
    except:
        # Dummy display class if init fails
        class DummyDisp:
            def fill(self, c): pass
            def text(self, s, x, y, c=1): pass
            def show(self): pass
        disp = DummyDisp()

# ---------------- RTC Init ----------------
try:
    rtc = DS3231(i2c)
    print("RTC found and initialized.")
    # Check for valid year
    t = rtc.datetime()
    if t is not None and t[0] < 2020:
        print("RTC year < 2020, resetting to default.")
        # Set to 2020-01-01 00:00:00
        rtc.datetime((2020, 1, 1, 2, 0, 0, 0, 0)) # Wed
    elif t is None:
        print("RTC communication failed during init.")
except Exception as e:
    print("RTC init failed:", str(e))
    rtc = None

def get_timestamp():
    """Get current unix timestamp from RTC or system time."""
    try:
        if rtc:
            t = rtc.datetime()
            if t is None:
                # I2C communication failed, fall back to system time
                return time.time()
            # Check year again just in case
            if t[0] < 2020:
                 rtc.datetime((2020, 1, 1, 2, 0, 0, 0, 0))
                 t = rtc.datetime()
                 if t is None:
                     return time.time()
            # DS3231: (year, month, day, weekday, hour, minute, second, subsecond)
            # Calculate Unix timestamp manually (seconds since 1970-01-01)
            # Simple approximation - good enough for relative time tracking
            year, month, day, weekday, hour, minute, second, subsec = t

            # Days since epoch (1970-01-01)
            # Simplified calculation - assumes 365.25 days/year average
            days = (year - 1970) * 365 + (year - 1969) // 4  # Account for leap years

            # Add days for months (approximate - doesn't account for exact month lengths)
            month_days = [0, 31, 59, 90, 120, 151, 181, 212, 243, 273, 304, 334]
            if month > 0 and month <= 12:
                days += month_days[month - 1]

            # Add current day
            days += day - 1

            # Convert to seconds and add time of day
            timestamp = days * 86400 + hour * 3600 + minute * 60 + second
            return timestamp
        else:
            return time.time()
    except Exception as e:
        print("RTC read error:", str(e))
        return time.time()

def get_time_string():
    """Return formatted time string YY-MM-DD HH:MM:SS"""
    if rtc:
        t = rtc.datetime()
        if t is not None:
            return "{:02d}{:02d}{:02d} {:02d}:{:02d}:{:02d}z".format(
                t[0]%100, t[1], t[2], t[4], t[5], t[6])
    # Fall back to system time if RTC fails or returns None
    t = time.localtime()
    return "{:02d}{:02d}{:02d} {:02d}:{:02d}:{:02d}z".format(
        t[0]%100, t[1], t[2], t[3], t[4], t[5])

def setup_datetime():
    """Prompt user to set date and time on startup."""
    global last_detent, raw_count

    if not rtc:
        print("No RTC found, skipping time setup.")
        return

    print("Entering Date/Time Setup...")
    print("Press button immediately to skip...")

    # Give user 2 seconds to skip
    skip_start = time.ticks_ms()
    while time.ticks_diff(time.ticks_ms(), skip_start) < 2000:
        if SW.value() == 0:  # Button pressed
            print("Skipping date/time setup")
            time.sleep_ms(200)
            while SW.value() == 0: time.sleep_ms(10)  # Wait for release
            return
        time.sleep_ms(50)

    # Get current time or default
    t = rtc.datetime()
    if t is None:
        # I2C communication failed, use defaults
        print("RTC communication failed, using defaults.")
        t = (2020, 1, 1, 0, 0, 0, 0, 0)
    # (year, month, day, weekday, hour, minute, second, subsecond)
    # Mutable list for editing: [year, month, day, hour, minute, second]
    dt = [t[0], t[1], t[2], t[4], t[5], t[6]]

    fields = [
        ("Year",   2020, 2099),
        ("Month",  1, 12),
        ("Day",    1, 31),
        ("Hour",   0, 23),
        ("Minute", 0, 59),
        ("Second", 0, 59)
    ]

    # Reset encoder for setup
    raw_count = 0
    last_detent = 0

    for i, (name, min_val, max_val) in enumerate(fields):
        # Reset encoder for each field to avoid jumps
        raw_count = 0
        last_detent = 0
        current_val = dt[i]

        while True:
            # Encoder handling
            irq = machine.disable_irq(); rc = raw_count; machine.enable_irq(irq)
            d = rc // DETENT_DIV

            if d != last_detent:
                delta = d - last_detent
                last_detent = d
                current_mode.on_encoder_rotate(delta)
                current_val += delta
                # Wrap or clamp? Let's clamp for Year, wrap for others maybe?
                # Simple clamping is safer for UI
                current_val = max(min_val, min(max_val, current_val))

            # Display
            try:
                disp.fill(0)
                disp.text("Set " + name + ":", 0, 0)
                disp.text("{}".format(current_val), 0, 16)
                disp.text("Click to Next", 0, 50)
                disp.show()
            except OSError as e:
                # OLED timeout - continue without display
                print(f"Display error (continuing): {e}")

            # Button handling
            if SW.value() == 0: # Pressed
                time.sleep_ms(DEBOUNCE_MS) # Debounce
                while SW.value() == 0: time.sleep_ms(10) # Wait for release
                dt[i] = current_val
                break # Next field

            time.sleep_ms(20)

    # Save to RTC
    # (year, month, day, weekday, hour, minute, second, subsecond)
    # We need to calculate weekday. simple approach or just set to 0 (Mon)
    # DS3231 calculates weekday automatically if running, but setting it might be needed.
    # Let's use a dummy weekday 0.
    new_t = (dt[0], dt[1], dt[2], 0, dt[3], dt[4], dt[5], 0)
    rtc.datetime(new_t)
    print("Time set to:", get_time_string())

    # Clear display
    try:
        disp.fill(0)
        disp.show()
    except OSError:
        pass  # Ignore display errors

# ---------------- Motor Initialization ----------------
print("="*60)
print("Initializing DYNAMIXEL motors...")
print("="*60)

# Import Extended Mode utilities
from dynamixel_extended_utils import set_extended_mode

try:
    # Configure motors for Extended Position Mode (Mode 4)
    # This must be done before creating DynamixelMotor instances
    print("\nConfiguring motors for Extended Position Mode...")

    print(f"\n1. Configuring AoV motor (ID {AOV_MOTOR_ID})...")
    if not set_extended_mode(AOV_MOTOR_ID):
        raise RuntimeError(f"Failed to configure AoV motor (ID {AOV_MOTOR_ID}) for Extended Position Mode")

    print(f"\n2. Configuring EQX motor (ID {EQX_MOTOR_ID})...")
    if not set_extended_mode(EQX_MOTOR_ID):
        raise RuntimeError(f"Failed to configure EQX motor (ID {EQX_MOTOR_ID}) for Extended Position Mode")

    print("\n✓ Motors configured for Extended Position Mode\n")

    # Now initialize motor objects
    print(f"3. Initializing AoV motor object...")
    aov_motor = DynamixelMotor(AOV_MOTOR_ID, "AoV", gear_ratio=AOV_GEAR_RATIO)
    print("   ✓ AoV motor ready")

    print(f"\n4. Initializing EQX motor object...")
    eqx_motor = DynamixelMotor(EQX_MOTOR_ID, "EQX", gear_ratio=EQX_GEAR_RATIO)
    print("   ✓ EQX motor ready")

    print("\n✓ Motors initialized successfully\n")

    # Set speed limits to prevent satellite from moving too fast
    print("Setting speed limits...")
    print("  (Higher values = slower, safer movement)")
    aov_motor.set_speed_limit(velocity=MAX_AOV_SPEED)  # Slower for AoV (visible pointer)
    eqx_motor.set_speed_limit(velocity=MAX_EQX_SPEED)  # Moderate for EQX (geared, slower anyway)
    print()

    # LED Flash Test - Visual motor identification without movement
    print("="*60)
    print("MOTOR ID TEST - LED Flash")
    print("="*60)
    disp.fill(0)
    disp.text("MOTOR TEST", 0, 0)
    disp.text("LED Flash...", 0, 16)
    disp.show()

    print("\nFlashing LEDs for motor identification...")
    print(f"  EQX Motor (ID {EQX_MOTOR_ID}): 1 flash")
    print(f"  AoV Motor (ID {AOV_MOTOR_ID}): 2 flashes")

    # Flash EQX motor LED once
    disp.fill(0)
    disp.text("MOTOR TEST", 0, 0)
    disp.text(f"EQX (ID {EQX_MOTOR_ID})", 0, 16)
    disp.text("Flash x1", 0, 32)
    disp.show()

    success = eqx_motor.flash_led(count=1, on_time_ms=50, off_time_ms=50)
    if success:
        print(f"  ✓ EQX motor LED flashed")
    else:
        print(f"  ✗ EQX motor LED flash failed")

    time.sleep_ms(500)  # Pause between motors

    # Flash AoV motor LED twice
    disp.fill(0)
    disp.text("MOTOR TEST", 0, 0)
    disp.text(f"AoV (ID {AOV_MOTOR_ID})", 0, 16)
    disp.text("Flash x2", 0, 32)
    disp.show()

    success = aov_motor.flash_led(count=2, on_time_ms=50, off_time_ms=50)
    if success:
        print(f"  ✓ AoV motor LED flashed")
    else:
        print(f"  ✗ AoV motor LED flash failed")

    time.sleep_ms(500)

    print("\n✓ Motor ID test complete\n")
    print("="*60)
    disp.fill(0)
    disp.text("MOTOR TEST", 0, 0)
    disp.text("Complete!", 0, 16)
    disp.show()
    time.sleep(1)

except RuntimeError as e:
    print(f"\n✗ Motor initialization failed: {e}")
    print("Cannot proceed without motors. Halting.")
    print("\nTroubleshooting:")
    print("  1. Check UART connections (GP0=TX, GP1=RX, GP2=DIR)")
    print("  2. Verify 74HC126 buffer wiring")
    print("  3. Check motor power (5V supply)")
    print(f"  4. Verify motor IDs (should be {AOV_MOTOR_ID} and {EQX_MOTOR_ID})")
    print("  5. Run test_two_motors.py to verify communication")
    while True:
        disp.fill(0)
        disp.text("MOTOR ERROR", 0, 0)
        disp.text("Check wiring", 0, 16)
        disp.text(str(e)[:16], 0, 32)
        disp.text("See console", 0, 48)
        disp.show()
        time.sleep(1)
except Exception as e:
    print(f"\n✗ Unexpected error: {e}")
    print(f"   Type: {type(e).__name__}")
    import sys
    sys.print_exception(e)
    while True:
        disp.fill(0)
        disp.text("ERROR", 0, 0)
        disp.text(str(e)[:16], 0, 16)
        disp.text("See console", 0, 32)
        disp.show()
        time.sleep(1)

# ---------------- Encoder + Buttons ----------------
A  = Pin(6, Pin.IN, Pin.PULL_UP)
B  = Pin(7, Pin.IN, Pin.PULL_UP)
SW = Pin(8, Pin.IN, Pin.PULL_UP)
BACK_BTN = Pin(9, Pin.IN, Pin.PULL_UP)
CONFIRM_BTN = Pin(10, Pin.IN, Pin.PULL_UP)

state = (A.value()<<1) | B.value()
raw_count = 0
TRANS = (0,+1,-1,0,  -1,0,0,+1,  +1,0,0,-1,  0,-1,+1,0)

def _enc_isr(_):
    global state, raw_count
    s = (A.value()<<1) | B.value()
    d = TRANS[(state<<2)|s]
    raw_count -= d  # Reverse direction
    state = s

A.irq(trigger=Pin.IRQ_RISING|Pin.IRQ_FALLING, handler=_enc_isr)
B.irq(trigger=Pin.IRQ_RISING|Pin.IRQ_FALLING, handler=_enc_isr)

# ---------------- Orbital Mechanics ----------------
def compute_period_from_altitude(altitude_km):
    """Compute orbital period from altitude using Kepler's third law."""
    a = altitude_km + EARTH_RADIUS  # semi-major axis
    # T = 2π√(a³/μ)
    period_sec = 2 * math.pi * math.sqrt(a**3 / EARTH_MU)
    period_min = period_sec / 60.0
    return period_min

def compute_altitude_from_period(period_min):
    """Compute orbital altitude from period using Kepler's third law."""
    period_sec = period_min * 60.0
    # T = 2π√(a³/μ) => a = (μT²/4π²)^(1/3)
    a = (EARTH_MU * period_sec**2 / (4 * math.pi**2)) ** (1.0/3.0)
    altitude = a - EARTH_RADIUS
    return altitude, a

def compute_eqx_rate_j2(altitude_km, inclination_deg=51.6):
    """Compute EQX rate in Earth-fixed frame (deg/day).

    The Orbigator operates in an almost-ECI (Earth-Centered Inertial) frame:
    - The globe rotates at 360°/sidereal day (Earth's rotation)
    - The orbital plane precesses due to J2 (~5°/day for ISS)

    Total EQX rate ≈ 360°/sidereal day + J2 precession
    Motor position is wrapped modulo 360° to keep within one revolution.
    """
    a = altitude_km + EARTH_RADIUS
    inc_rad = math.radians(inclination_deg)

    # Mean motion (rad/s)
    n = math.sqrt(EARTH_MU / (a**3))

    # J2 precession rate (rad/s) - nodal precession of orbital plane
    # dΩ/dt = -1.5 * n * J2 * (Re/a)² * cos(i)
    eqx_rate_rad_s = -1.5 * n * EARTH_J2 * (EARTH_RADIUS / a)**2 * math.cos(inc_rad)

    # Convert to deg/day
    eqx_j2_deg_day = math.degrees(eqx_rate_rad_s) * 86400

    # Add Earth's rotation (360° per sidereal day)
    # Total rate in Earth-fixed frame
    # NEGATED: Motor horn faces down, so positive rotation = west (wrong!)
    # We want eastward rotation (sun rises in east), so negate the rate
    eqx_total_deg_day = -(eqx_j2_deg_day + EARTH_ROTATION_DEG_DAY)

    return eqx_total_deg_day

def compute_motor_rates(altitude_km):
    """Compute motor rotation rates for given altitude."""
    # Compute period from altitude
    period_min = compute_period_from_altitude(altitude_km)

    # AOV: 1 revolution per orbital period (in degrees per second)
    aov_deg_per_sec = 360.0 / (period_min * 60.0)

    # EQX: rate from J2 effect + Earth rotation (in degrees per second)
    eqx_rate_deg_day = compute_eqx_rate_j2(altitude_km)
    eqx_deg_per_sec = eqx_rate_deg_day / 86400.0

    return aov_deg_per_sec, eqx_deg_per_sec, eqx_rate_deg_day, period_min

def wrap_aov_position(current_deg, target_deg):
    """
    Wrap AoV target position to stay within ±180° of current position.

    CRITICAL: AoV motor should NEVER move more than one revolution!
    The pointer arm is mechanically constrained, so we must always
    take the shortest path to the target position.

    Args:
        current_deg: Current AoV position in degrees
        target_deg: Desired AoV position in degrees

    Returns:
        Wrapped target position that's within ±180° of current position
    """
    # Calculate the difference
    diff = target_deg - current_deg

    # Normalize difference to -180 to +180 range
    while diff > 180:
        diff -= 360
    while diff < -180:
        diff += 360

    # Return current position + shortest path
    wrapped_target = current_deg + diff

    return wrapped_target

# ---------------- Persistence ----------------
def save_state():
    """Save current orbital parameters to config file."""
    try:
        config = {
            "altitude_km": orbital_altitude_km,
            "eqx_deg": eqx_position_deg,
            "aov_deg": aov_position_deg,
            "timestamp": get_timestamp()
        }
        with open(CONFIG_FILE, "w") as f:
            json.dump(config, f)
        print("State saved:", config)
    except Exception as e:
        print("Error saving state:", e)

def load_state():
    """Load orbital parameters from config file."""
    global orbital_altitude_km, eqx_position_deg, aov_position_deg
    global orbital_period_min

    # CRITICAL: Read current motor positions BEFORE any commands
    # This prevents motors from jumping on startup
    print("\nReading current motor positions...")
    current_eqx_deg = eqx_motor.get_angle_degrees()
    current_aov_deg = aov_motor.get_angle_degrees()

    if current_eqx_deg is None or current_aov_deg is None:
        print("✗ Failed to read motor positions!")
        # Use defaults if we can't read
        eqx_position_deg = 0.0
        aov_position_deg = 0.0
        orbital_period_min = compute_period_from_altitude(orbital_altitude_km)
        return

    print(f"  Current EQX: {current_eqx_deg:.2f}°")
    print(f"  Current AoV: {current_aov_deg:.2f}°")

    try:
        with open(CONFIG_FILE, "r") as f:
            config = json.load(f)

        orbital_altitude_km = config.get("altitude_km", 400.0)
        eqx_position_deg = config.get("eqx_deg", 0.0)
        aov_position_deg = config.get("aov_deg", 0.0)
        saved_timestamp = config.get("timestamp", 0)

        # Update computed values
        orbital_period_min = compute_period_from_altitude(orbital_altitude_km)

        # Calculate catch-up if we have a valid timestamp
        current_timestamp = get_timestamp()
        delta_t = current_timestamp - saved_timestamp

        if delta_t > 0 and saved_timestamp > 0:
            print("Catching up {} seconds...".format(delta_t))

            # Compute rates for catch-up
            _, _, eqx_rate_deg_day, period_min = compute_motor_rates(orbital_altitude_km)

            # EQX catch-up (can be any amount - continuous rotation)
            eqx_rate_deg_sec = eqx_rate_deg_day / 86400.0
            eqx_delta = eqx_rate_deg_sec * delta_t
            target_eqx_deg = eqx_position_deg + eqx_delta

            # AOV catch-up
            aov_rate_deg_sec = 360.0 / (period_min * 60.0)
            aov_delta = aov_rate_deg_sec * delta_t
            target_aov_deg = aov_position_deg + aov_delta

            # CRITICAL: Wrap AoV to prevent multi-revolution movement
            # AoV should NEVER move more than ±180° from current position
            target_aov_deg = wrap_aov_position(current_aov_deg, target_aov_deg)
            aov_diff = target_aov_deg - current_aov_deg

            # Move motors to catch-up positions using shortest path
            target_eqx_wrapped = target_eqx_deg % 360.0
            target_aov_wrapped = target_aov_deg % 360.0

            print(f"Moving EQX: {current_eqx_deg:.2f}° → target: {target_eqx_wrapped:.2f}°")
            eqx_motor.set_nearest_degrees(target_eqx_wrapped)
            time.sleep(0.5)

            print(f"Moving AoV: {current_aov_deg:.2f}° → target: {target_aov_wrapped:.2f}° (Δ={aov_diff:+.2f}°)")
            aov_motor.set_nearest_degrees(target_aov_wrapped)
            time.sleep(0.5)

            # Update positions (wrapped for display)
            eqx_position_deg = target_eqx_wrapped
            aov_position_deg = target_aov_deg % 360.0

            print("✓ Catch-up complete")
        else:
            # No catch-up needed - use current motor positions as baseline
            print("No catch-up needed (no saved timestamp or delta_t <= 0)")
            eqx_position_deg = current_eqx_deg
            aov_position_deg = current_aov_deg

        print("State loaded:", config)
    except OSError:
        print("No config file found, using defaults.")
        # Use current motor positions as baseline
        eqx_position_deg = current_eqx_deg
        aov_position_deg = current_aov_deg
    except Exception as e:
        print("Error loading state:", e)

# ---------------- State Machine ----------------
# State 0: Set altitude
# State 1: Set EQX position
# State 2: Set AOV position
# State 3: Run simulation
current_state = 3  # Start in running state for debugging (normally 0)
last_button_time = 0

# Orbital parameters
orbital_altitude_km = 400.0  # Start at ISS altitude
orbital_period_min = 0.0  # Computed from altitude
eqx_position_deg = 0.0
aov_position_deg = 0.0
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

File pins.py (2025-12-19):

# pins.py - Orbigator GPIO Assignment Module
# Raspberry Pi Pico 2 with DYNAMIXEL XL330-M288-T Motors
# Aligned with orbigator.py and ORBIGATOR_PIN_ASSIGNMENTS.txt

from machine import Pin

# ---------------------------
# DYNAMIXEL Communication (UART0 + 74HC126 Buffer)
# ---------------------------
UART_TX = 0      # GP0 - UART0 TX → 74HC126 Pin 2 (1A)
UART_RX = 1      # GP1 - UART0 RX → DYNAMIXEL DATA line
UART_DIR = 2     # GP2 - Direction Control → 74HC126 Pin 1 (1OE)

# ---------------------------
# I2C Bus (OLED + DS3231 RTC)
# ---------------------------
I2C_SDA = 4      # GP4 - I2C0 SDA (shared: OLED + RTC)
I2C_SCL = 5      # GP5 - I2C0 SCL (shared: OLED + RTC)

# ---------------------------
# Rotary Encoder
# ---------------------------
ENC_A = 6        # GP6 - Encoder Phase A (with internal pull-up)
ENC_B = 7        # GP7 - Encoder Phase B (with internal pull-up)
ENC_SW = 8       # GP8 - Encoder Switch (with internal pull-up)

# ---------------------------
# Helper Pin Constructors
# ---------------------------
# UART pins (managed by UART peripheral, typically not constructed manually)
uart_dir_pin = Pin(UART_DIR, Pin.OUT)

# I2C pins (managed by I2C peripheral)
# i2c_sda_pin = Pin(I2C_SDA, Pin.OUT, Pin.OPEN_DRAIN)
# i2c_scl_pin = Pin(I2C_SCL, Pin.OUT, Pin.OPEN_DRAIN)

# Encoder pins
enc_a_pin = Pin(ENC_A, Pin.IN, Pin.PULL_UP)
enc_b_pin = Pin(ENC_B, Pin.IN, Pin.PULL_UP)
enc_sw_pin = Pin(ENC_SW, Pin.IN, Pin.PULL_UP)

# ---------------------------
# Motor Configuration
# ---------------------------
# DYNAMIXEL Motor IDs
MOTOR_ID_AOV = 1  # Argument of Vehicle (direct drive)
MOTOR_ID_EQX = 2  # Equator crossing (11T → 120T gearing)

# Gear Ratios
EQX_GEAR_RATIO = 120.0 / 11.0  # Ring gear / Drive gear
AOV_GEAR_RATIO = 1.0            # Direct drive

# ---------------------------
# UART Configuration
# ---------------------------
UART_BAUD = 57600
UART_BITS = 8
UART_PARITY = None
UART_STOP = 1

# ---------------------------
# I2C Configuration
# ---------------------------
I2C_FREQ = 100_000  # 100 kHz for reliability with ChronoDot/DS3231

# I2C Addresses
OLED_ADDR = 0x3C    # OLED Display (SH1106/SSD1306)
RTC_ADDR = 0x68     # DS3231 RTC (ChronoDot)

# ---------------------------
# Encoder Configuration
# ---------------------------
DETENT_DIV = 2      # Encoder counts per detent (for responsiveness)
DEBOUNCE_MS = 200   # Button debounce time in milliseconds

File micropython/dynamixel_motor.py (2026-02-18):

"""
DYNAMIXEL Motor - Extended Position Mode with EQX Recovery
==========================================================
Supports multi-turn positioning (>360°) and RTC SRAM recovery for EQX.
"""

from dynamixel_extended_utils import (
    read_present_position, ping_motor
)
import time
import struct


class DynamixelMotor:
    """Dynamixel motor controller with extended position mode and EQX recovery."""
    
    # Constants
    TICKS_PER_REV = 4096
    TICKS_PER_DEGREE = 4096.0 / 360.0
    
    # Register addresses
    ADDR_TORQUE_ENABLE = 64
    ADDR_GOAL_POSITION = 116
    ADDR_PROFILE_VELOCITY = 112
    ADDR_POSITION_P_GAIN = 84
    ADDR_POSITION_I_GAIN = 82
    ADDR_POSITION_D_GAIN = 80
    
    # SRAM Checkpoint Constants
    SRAM_MAGIC = 0xDEAD       # V1: wrapped degrees (legacy)
    SRAM_MAGIC_V2 = 0xBEEF   # V2: absolute ticks
    SRAM_ADDR_EQX = 0x14
    CHECKPOINT_INTERVAL_TICKS = 512  # 45 degrees
    
    def __init__(self, motor_id, name, gear_ratio=1.0, rtc=None, 
                 offset_degrees=0.0, direction=None, recovery_direction=1,
                 last_known_pos=None, last_abs_ticks=None):
        """
        Initialize motor with 'mod 4096' hardware and absolute software tracking.
        """
        self.motor_id = motor_id
        self.name = name
        self.gear_ratio = gear_ratio
        self.rtc = rtc
        self.offset_degrees = offset_degrees
        self.direction = direction # None (Any), 1 (Forward Only), -1 (Reverse Only)
        self.recovery_direction = recovery_direction
        self._last_checkpoint_ticks = 0
        
        # 1. Reset hardware counter to current phase (0-4095)
        self._init_hardware()
        
        # 2. Read hardware starting point (will be 0-4095 due to reset)
        h_pos = read_present_position(motor_id)
        if h_pos is None:
            raise RuntimeError(f"Failed to read motor {motor_id}")
            
        # 3. Recover software absolute position
        if self.name == "EQX":
            if last_abs_ticks is not None and last_abs_ticks != 0:
                # Primary: bounded-delta from saved abs ticks (test-proven)
                self._raw_ticks = self._recover_from_abs_ticks(h_pos, last_abs_ticks)
            elif self.rtc:
                # Fallback: SRAM checkpoint recovery
                self._raw_ticks = self._try_recovery(h_pos)
            else:
                self._raw_ticks = h_pos
        else:
            self._raw_ticks = h_pos
            
        # 4. Calculate hardware/software offset to prevent jumps
        # hw_pos = sw_pos + offset => offset = hw_pos - sw_pos
        self._hw_offset = h_pos - self._raw_ticks
            
        self._last_checkpoint_ticks = self._raw_ticks
        self.output_degrees = (self._raw_ticks / self.TICKS_PER_REV) * 360.0 / self.gear_ratio
        
        print(f"  [{name}] Init: software={self._raw_ticks}, hardware={h_pos}, offset={self._hw_offset}")

    @staticmethod
    def wrap_180(deg):
        """Wrap degrees to +/- 180 range."""
        return (deg + 180) % 360 - 180

    def _init_hardware(self):
        """Reset hardware counter to phase (0-4095)."""
        from dynamixel_extended_utils import write_byte, clear_multi_turn, ping_motor
        
        if not ping_motor(self.motor_id):
            print(f"  [{self.name}] Error: Motor {self.motor_id} not responding")
            return

        # FORCE HARDWARE RESET TO PHASE (0-4095)
        write_byte(self.motor_id, 64, 0) # Torque OFF
        time.sleep_ms(50)
        
        # Try Instruction 0x0A (Clear Multi-Turn) - clean way to reset counter
        if clear_multi_turn(self.motor_id):
             print(f"  [{self.name}] Counter cleared via Instruction 0x0A")
        else:
            # Fallback for older firmware
            write_byte(self.motor_id, 11, 3) # Mode 3 (Standard)
            time.sleep_ms(100)
            write_byte(self.motor_id, 11, 4) # Mode 4 (Extended)
            time.sleep_ms(100)
            print(f"  [{self.name}] Counter reset via Mode toggle")
        
        write_byte(self.motor_id, 64, 1) # Torque ON
        time.sleep_ms(50)

    def _recover_from_abs_ticks(self, current_phase, last_abs_ticks):
        """
        Recover absolute position using bounded-delta (3-candidate) algorithm.
        Matches eqx_power_fail_test.py / orb_utils.calculate_absolute_position().
        """
        CPR = self.TICKS_PER_REV
        raw = current_phase % CPR
        revs = last_abs_ticks // CPR
        candidates = [
            (revs - 1) * CPR + raw,
            revs * CPR + raw,
            (revs + 1) * CPR + raw
        ]
        recovered = min(candidates, key=lambda x: abs(x - last_abs_ticks))
        print(f"  [{self.name}] ABS TICK RECOVERY: cached={last_abs_ticks}, phase={raw}, recovered={recovered} (delta={recovered - last_abs_ticks})")
        return recovered

    def _try_recovery(self, current_phase_ticks):
        """Recover from RTC SRAM checkpoint (fallback when no abs_ticks from state)."""
        data = self.rtc.read_sram(self.SRAM_ADDR_EQX, 12)
        if not data:
            print(f"  [{self.name}] No SRAM data found")
            return current_phase_ticks

        try:
            timestamp, magic, s_phase = struct.unpack("<IHH", data[:8])

            if magic == self.SRAM_MAGIC_V2:
                # V2: absolute ticks stored - use bounded-delta
                saved_abs = struct.unpack("<i", data[8:12])[0]
                print(f"  [{self.name}] SRAM V2 checkpoint (T={timestamp})")
                return self._recover_from_abs_ticks(current_phase_ticks, saved_abs)
            elif magic == self.SRAM_MAGIC:
                # V1 legacy: wrapped degrees - phase-stitch (best effort)
                s_deg = struct.unpack("<f", data[8:12])[0]
                CPR = self.TICKS_PER_REV
                delta_ticks = (current_phase_ticks - s_phase + CPR//2) % CPR - CPR//2
                delta_gear_deg = (delta_ticks / self.gear_ratio / self.TICKS_PER_DEGREE)
                recovered_eqx = self.wrap_180(s_deg + delta_gear_deg)
                recovered_abs_ticks = int(recovered_eqx * self.gear_ratio * self.TICKS_PER_DEGREE)
                print(f"  [{self.name}] SRAM V1 LEGACY (T={timestamp}): {s_deg:.2f}° + {delta_gear_deg:.2f}° = {recovered_eqx:.2f}°")
                return recovered_abs_ticks
            else:
                print(f"  [{self.name}] SRAM magic mismatch: {magic:04X}")
                return current_phase_ticks
        except Exception as e:
            print(f"  [{self.name}] Recovery error: {e}")
            return current_phase_ticks

    def _save_checkpoint(self, h_pos_sync=None):
        """Save absolute ticks + phase to RTC SRAM (V2 format)."""
        if self.rtc and self.name == "EQX":
            import utime
            dt = self.rtc.datetime()
            now = utime.mktime(dt) if dt else 0
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

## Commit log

2025-07-25 added schematics
    [full_assembly.scad]
2025-07-28 added screenshots
    [full_assembly.scad]
2025-07-28 added satellite stl file
    [sat_model_2.stl]
2025-11-17 scad work
    [aov_arm.scad, flange.scad, full_assembly.scad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]
2025-11-23 added stl files
    [RingLock.stl, aov_arm.stl, aov_arm_2stack.stl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]
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2025-11-23 Add CLI arguments to STL-to-STEP converter
    - --all: convert all files except those in skip list
    - --list: show available STL files and skip status
    - Positional args: convert specific files by name
    - SKIP_LIST configurable at top of script
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2025-11-23 Simplify STL-to-STEP script to just use skip list
    Removed environment variable complexity - just converts all STL files
    except those in SKIP_LIST.
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2025-11-23 Add render file for aov_arm with assembly orientation
    [render_aov_arm.scad]
2025-11-23 Update render_aov_arm with full assembly transformation
    [render_aov_arm.scad]
2025-11-23 minor bugfix
    [render_aov_arm.scad, sat_model_2.stl]
2025-11-23 Add in-situ rendering for all assembly components
    - render_in_situ.scad: Master file with all component transformations
    - render_all_in_situ.sh: Batch script to render all components
    - stls_in_situ/: Output directory for positioned STL files
    Components include: aov_arm, aov_motor_mount, sled, ring_gear,
    drive_gear, base_with_1010_hole, RingLock, idler, spring_arms, pico
    [render_in_situ.scad]
2025-11-23 Revert "Add in-situ rendering for all assembly components"
    This reverts commit 74e6fdb57ab42eb3366b8efe9cabed848b9f8aa6.
    [render_in_situ.scad]
2025-11-23 Update render_aov_arm to use 'use' instead of 'include'
    [render_aov_arm.scad]
2025-11-23 Add render file for aov_motor_mount in assembly position
    [render_aov_motor_mount.scad]
2025-11-23 Add render file for base_with_1010_hole in assembly position
    [render_base_with_1010_hole.scad]
2025-11-23 Add render file for ring gear in assembly position
    [render_ring_gear.scad]
2025-11-23 Add render file for 1010 aluminum extrusion in assembly position
    [render_1010_extrusion.scad]
2025-11-23 added in_situ step files
    [1010_extrusion.step, RingLock.step, aov_arm.step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]
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2025-12-01 Fix DS3231 I2C communication reliability
    - Switch from readfrom_mem to write-then-read method (more reliable)
    - Lower I2C frequency to 100kHz for better ChronoDot compatibility
    - Update both datetime() and temperature() methods
    - Fixes EIO error when reading from DS3231 registers
    [ds3231.py]
2025-12-02 feat: Add initial Orbigator application with motor control, OLED, RTC, orbital calculations, supporting mechanical designs, schematics, and updated MicroPython scripts.
    [1010_extrusion.stl, RingLock.stl, aov_arm.stl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]
2025-12-02 Add long press time setting with DS3231 RTC integration
    - Long press (1s) encoder button enters time-setting mode
    - Short press cycles through states or time fields
    - Encoder adjusts hour/minute/year/month/day fields
    - Blinking cursor shows active field
    - Saves to DS3231 RTC on long press exit
    - Lower I2C frequency to 100kHz for RTC compatibility
    - State 3: Time setting mode with OLED interface
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2025-12-02 fix: Refactor button handling to non-blocking state machine for long press detection
    - Replace blocking while loop with state machine approach
    - Add button_down and button_press_start state tracking
    - Detect press/release transitions across loop iterations
    - Check press duration on release to determine short vs long press
    - Prevents main loop blocking during button press
    - Add long_press_test.py diagnostic script
    [orbigator.py]
2025-12-02 fix: Use str() wrapper for RTC exception to avoid printing errors
    [orbigator.py]
2025-12-02 fix: Replace time.mktime() with manual timestamp calculation
    - time.mktime() may not be available in all MicroPython builds
    - Implement manual Unix timestamp calculation from datetime tuple
    - Uses simplified day counting with leap year approximation
    - Good enough for relative time tracking in orbital simulation
    - Fixes 'name time isn't defined' error during RTC initialization
    [orbigator.py]
2025-12-02 fix: Add missing import time to ds3231.py and clean up debug statements
    - ds3231.py was missing 'import time' causing NameError during RTC init
    - Removed debug print statements from orbigator.py RTC initialization
    - RTC now initializes correctly with ChronoDot/DS3231 hardware
    [ds3231.py]
2025-12-07 Add comprehensive DYNAMIXEL wiring verification checklist
    Created detailed checklist to verify DYNAMIXEL XL330 wiring is correct:
    - Pre-flight power and ground connection checks
    - SN74HC126N buffer wiring verification
    - DATA BUS connection verification
    - Continuity tests (power off)
    - Voltage tests (power on)
    - Servo configuration steps
    - Functional communication and motion tests
    - Common wiring mistakes to avoid
    - Signal flow verification diagrams
    This provides step-by-step guidance to ensure the new DYNAMIXEL
    wiring is correctly implemented before powering on the system.
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2025-12-16 Update drive shaft screw depth and add documentation
    [dynamixel_drive_shaft.stl, dynamixel_motor.scad, dynamixel_xl330_gear_adapter.scad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]
2025-12-16 Add 74x126 buffer documentation and fix DS3231 RTC issues
    - Added comprehensive 74x126 tri-state buffer section to dry lab guide
    - Included pinout diagram with detailed pin descriptions
    - Explained half-duplex UART communication requirements
    - Fixed DS3231 init scan issue (commented out redundant check)
    - Updated ds3231_test.py to use local module instead of urtc
    - Lowered I2C frequency to 100kHz for better reliability
    [ds3231.py]
2025-12-18 Orbigator Dynamixel Rewrite - Complete Implementation
    Major Changes:
    - Rewrote orbigator.py to use DYNAMIXEL XL330-M288-T motors (745 lines, down from 800)
    - Created motor abstraction layer (dynamixel_motor.py) with gear ratio support
    - Motor ID assignments: ID 1 = AoV (direct), ID 2 = LAN (10.909:1 geared)
    - Removed all stepper motor code (~400 lines)
    - Simplified motion control (motors handle acceleration internally)
    New Features:
    - Position persistence across power cycles
    - Continuous rotation (Extended Position Mode 4, no 360° limit)
    - Encoder nudging in running mode (1° per detent, DETENT_DIV=2)
    - AoV catch-up limited to ±180° (shortest path)
    - Startup motor test (±10° for LAN, 1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
    [dynamixel_extended_utils.py, dynamixel_motor.py, orbigator_kicad_netlist.py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]
2025-12-19 Add run mode sub-states and debug optimizations
    - Renamed LAN to EQX throughout codebase for clarity
    - Added Extended Position Mode configuration on startup (critical fix)
    - Implemented sub-mode toggle in State 3: nudge AoV (A>) and nudge EQX (X>)
    - Fixed EQX nudging by reordering target calculations after encoder check
    - Added debug mode: start in State 3, skip clock setup, remove movement test
    - Adjusted speed limits: both motors set to 50 for moderate speed
    - Created EQX_debug.py standalone test script
    - Added development workflow and tuning documentation
    [dynamixel_aov_arm.scad, dynamixel_aov_arm.stl, dynamixel_drive_shaft.stl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]
2025-12-20 Fix motor control and I2C issues, add documentation
    Major fixes:
    - Add I2C pull-up resistors (4.7kΩ on SDA/SCL) to fix display glitching
    - Implement get_new_pos() for Extended Position Mode wrapping
    - Fix motor rate initialization bug when starting in state 3
    - Fix catch-up mechanism to prevent extreme motor movements
    - Reduce display update to 1Hz for better I2C performance
    Documentation:
    - Add NOTE_FOR_ANOOL_I2C_PULLUPS.txt with critical PCB requirements
    - Update ORBIGATOR_CIRCUIT_DIAGRAM.txt with pull-up resistors (R2, R3)
    - Update README_DYNAMIXEL_MOTORS.md with M2×8 screw specifications
    - Add schematic images: 74HC126 pinout, DC power jack, motor pinout, PCB layout
    - Add SESSION_NOTE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
    [base_with_1010_display.stl, display_encoder_board.scad, display_mount_test.stl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]
2025-12-21 Add KiCad starter package and motor wrapping fixes
    - Created comprehensive KiCad 8.x starter package in kicad/ directory
    - Project file with proper design rules
    - Detailed BOM with KiCad footprints
    - Complete netlist documentation
    - Step-by-step schematic creation guide
    - Directory structure matching WyoLum standards
    - Fixed AoV motor wrapping issue
    - Added get_new_pos() function for shortest-path movement
    - Created set_nearest_degrees() method in DynamixelMotor class
    - Updated all motor commands to use shortest path
    - Motors now correctly wrap around 0° (358° → 2° goes +4°, not -356°)
    - Updated RTC backup power documentation
    - Added supercapacitor option (0.47F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
    [dynamixel_extended_utils.py, dynamixel_motor.py, orbigator.py]
2025-12-21 Add KiCad PCB outline with centered mounting holes
    - Created orbigator.kicad_pcb with 55x70mm board outline
    - Board rotated 90° and centered on A4 sheet
    - Added 4x M3 mounting holes matching display board pattern
    - Holes positioned at (75.5,134), (75.5,163), (134.5,134), (134.5,163)
    - Hole pattern centered on board to align with display board
    - Added silkscreen text: 'Orbigator v1.0' and 'WyoLum'
    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
    [orbigator.kicad_pcb]
2025-12-21 Complete KiCad starter package with documentation
    Added comprehensive documentation and guides:
    - PCB_CHECKLIST.md: Complete design checklist from schematic to manufacturing
    - DESIGN_RULES.md: All design constraints and specifications
    - QUICK_REFERENCE.md: One-page critical information reference
    - GETTING_STARTED.md: Step-by-step guide for Anool
    - component_placement_guide.png: Visual placement diagram
    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
    [orbigator.kicad_sch]
2025-12-25 Add back/confirm buttons (GP9/GP10) and fix EQX motor direction
    - Added GP9 (Back button) and GP10 (Confirm button) to pin assignments
    - Updated component list to include new buttons
    - Fixed EQX motor direction (negated rate) - sun now rises in east
    - Added test_buttons.py for button verification
    - All buttons tested and working
    [orbigator.py]
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2025-12-25 Implement revolution-based persistence, shortest-path catch-up logic, and hardware safety limits. Update README.
    [ds323x.py, dynamixel_motor.py, homing.py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]
2025-12-25 Finalized Zulu time formatting, dynamic inclination control, and UI refinements. Updated README.
    [base_with_1010_display.stl, drive_gear.stl, dynamixel_aov_arm.scad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]
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2025-12-25 Fixed dead DigiKey links for JST-GH housings and crimp contacts.
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2025-12-25 Corrected JST-GH PCB header links in documentation.
2025-12-25 Switched PCB header links to Mouser for better availability/stability.
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2025-12-25 Added Zulu Time (Datetime) editor and boot-time RTC reset check to prompt for time if reset.
    [modes.py, orb_utils.py, orbigator.py]
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2025-12-25 Corrected encoder direction across all modes to ensure CW = Increase/Down.
    [modes.py]
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2025-12-25 Fixed AoV drift on Orbit re-entry by using saved positions as the catch-up anchor and saving state on exit.
    [modes.py, orb_utils.py]
2025-12-25 Fixed AoV drift by implementing high-resolution system time syncing and high-precision catch-up anchors.
    [modes.py, orb_utils.py, orbigator.py]
2025-12-25 Fixed NameError in orb_utils and successfully deployed high-precision timing logic.
    [modes.py, orb_utils.py]
2025-12-25 Fixed Orbit re-entry drift by anchoring catch-up to current motor position relative to elapsed time.
    [modes.py]
2025-12-25 Reverted AoV speed limit to 10.
    [modes.py, orbigator.py]
2025-12-25 Fixed AoV motor stop issue (FP32 precision fix).
    [modes.py, orb_globals.py, orb_utils.py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]
2025-12-25 Fixed all bugs: Reverse Orbit, Editor Lockup, and UI layout.
    [modes.py, orb_utils.py, orbigator.py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]
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2025-12-25 Implemented interrupt-driven button handling with event queue for improved UI responsiveness
    [.#full_assembly.scad]
2025-12-25 Implemented elliptical orbit support with Kepler's equation solver, variable velocity integration, and UI editors for eccentricity and periapsis
    [.#full_assembly.scad, full_assembly.scad]
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2025-12-25 Added SGP4 vs Plan13 comparison - discovered Plan13 has 7850km longitude error due to outdated GHAA constants (2014 vs 2025)
    [compare_sgp4_plan13.py]
2025-12-28 Update SGP4 logic, add web server, and expand documentation
    [base_with_1010_display.stl, display_encoder_board.scad, display_spacers.stl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]
2025-12-28 Optimize performance, implement live motor tuning, and add incremental sync scripts
    [dynamixel_aov_arm.scad, dynamixel_motor.scad, full_assembly.scad]
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2025-12-30 Fix NameError in boot sequence
    [orbigator.py]
2025-12-30 Mechanical: increase globe_interface_ring scale to 1.02 for better fit
    [full_assembly.scad]
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2025-12-30 UI: refined encoder acceleration (1.0 deg max) + Mechanical: 1.02 globe ring iteration
    [dynamixel_aov_arm.scad, sled.scad]
2025-12-30 UI: clean up catch-up display (fixed overlapping text)
    [modes.py]
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2026-01-03 Fix SGP4 accuracy: Implement integer-based time offsets and precise geodetic conversion
    [ntp_sync.py, orb_utils.py, propagators.py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]
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2026-01-03 Revert AoV speed limit to 2, keep torque enabled
    [orbigator.py]
2026-01-03 Fix SGP4 mapping: EQX formula and 2-digit year handling
    [propagators.py, satellite_position.py]
2026-01-03 feat: SGP4 precision fix, motor tuning, and config refactor
    [arm_aov.scad, assembly.scad, base.scad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]
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2026-01-07 Fix Motor Speed, SRAM Persistence, TrackLLMode, and Repo Cleanup
    [audit_sgp4_mapping.py, big_stepper_constant_jerk.py, compare_sgp4_plan13.py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]
2026-01-07 Fix Orbit Resume Jump (Time Slip Bug)
    [modes.py]
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2026-01-10 simple iss model added
    [display_encoder_board.scad, globe_interface.stl, globe_interface_1.005.stl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]
2026-01-10 acrylic globe insert added
    [antarctica.scad]
2026-01-11 PCB check parts placement
    [JST_EH_B3B-EH-A_1x03_P2.50mm_Vertical.step, OLED_Display1-F.Fab_.dxf, OLED_Display1.FCStd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]
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2026-01-12 PCB modified RTC layout
    [1056.step, DS3232.kicad_pcb, DS3232.kicad_sch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]
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2026-01-17 PCB layout please verify
    [orbigator.kicad_sch]
2026-01-31 v2 DISP_ENC flip corrected in PCB
    [5188 DS3231 RTC.step, DS3232.step, JST_EH_B3B-EH-A_1x03_P2.50mm_Vertical.step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]
2026-02-01 Fix motor position persistence & main loop structure
    - Fixed offset calculation in dynamixel_motor.py for power-cycle restoration
    - Fixed main loop: moved finally block outside while True to prevent running every iteration
    - Removed all periodic SRAM saves - now only saves on motor turn change
    - Fixed position normalization: removed duplicate assignment overwriting modulo
    - Added safety modulo in save_state() to guarantee 0-360° values
    - Updated LLA display to integer format with lon in -180/+180 range
    - Shifted SGP4Mode display down 2px to prevent text clipping
    - Added motor.on_turn_change callback for SRAM persistence
    [Custom_Wrench.scad, UM3_base_with_spring_mounts.3mf, antarctica.stl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]
2026-02-02 v2 Motor connectors flip 180 deg in PCB
    [orbigator-B_Cu.gbr, orbigator-B_Mask.gbr, orbigator-B_Silkscreen.gbr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]
2026-02-07 Fix EQX recovery, add DESIGN_DECISIONS.md, improve SGP4 display
    - Fixed bounded-delta recovery to always use shortest path
    - EQX d_mod=4095 now correctly interpreted as -1, not +4095
    - Added DESIGN_DECISIONS.md documenting motor control philosophy
    - SGP4Mode now shows 'Tracking ISS' on one line with AoV/EQX display
    - Fixed OrbitMode nudge logic (EQX nudge was moving AoV)
    - Added home() method to DynamixelMotor
    - Removed incorrect phase re-anchoring code
    - Various display and state persistence improvements
    [full_assembly.scad, full_assembly.stl, orbigator_pcb.scad]
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2026-02-08 Fix EQX tracking logic, motor speeds, and web server syntax
    [buttons.py, capabilities.py, dynamixel_extended_utils.py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]
2026-02-08 Fix EQX recovery: use test-proven bounded-delta algorithm
    The SRAM-only recovery wrapped degrees to ±180°, destroying multi-turn
    position info and causing large jumps on short power cycles. Now uses
    the 3-candidate bounded-delta algorithm from eqx_power_fail_test.py
    with abs_ticks from saved state (primary) or SRAM V2 checkpoint
    (fallback). Also adds missing absolute_ticks property so save_state
    actually persists non-zero tick counts.
    [dynamixel_motor.py]
2026-02-18 feat: Final Polish - TLE Updates, Homing Fix, Stiction Tuning, Splash Screen
    - TLE Updates: 12h cycle with background check
    - Homing: AoV -> 90° Zenith, Nearest Logic
    - Tuning: AoV PID P=1000/I=50 to fix stiction
    - UX: Splash Screen with countdown + sh1106 refactor
    - Safety: 5s boot delay
    - Refactor: Shared sh1106 driver
    [absolute_motor.py, audit_sgp4_mapping.py, capabilities.py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]
2026-02-22 feat: OLED burn-in prevention with menu-selectable timeout
    - sh1106: add sleep()/wake(), is_sleeping flag
    - orb_globals: add last_input_ticks, oled_timeout_ms (2min default)
    - modes: ModeStack sleeps after idle timeout, wakes on input
    - modes: ScreenTimeoutMode (1/2/5/10 min / Never)
    - modes: Screen Timeout item in SettingsMode
    - orbigator: DummyDisp has sleep/wake stubs, expose init errors
    [modes.py, orb_globals.py, orbigator.py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]
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2026-02-23 fix: overhead alert display polish
    - Remove N text label (keep pixel tick only)
    - Trail buffer: 300pts at 1Hz for full 5-min pass coverage
    - Display stays on during entire pass (reset idle timer each render)
    [modes.py, radar_display.py]
2026-02-23 fix: trail 1pt/min, 20-pt buffer (covers full pass to set)
    [radar_display.py]
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2026-02-23 fix: remove vertical divider line from radar display
    [radar_display.py]
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2026-02-25 fix: DS3231 → DS3232 in live docs
2026-02-27 Radar alert: predicted track (1px) + live dots (2x2), dynamic pass duration
    - overhead_watcher: alert stays active for full pass (no fixed timer), added pass_just_started flag
    - radar_display: predicted track (1px white) + live track (2x2 dots), replaces ring buffer
    - modes.py SGP4Mode: forward-propagates pass at 30s intervals on rise, feeds live points every tick
    - test updated for new API with dedup and predicted-track assertions
    [modes.py, radar_display.py]
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2026-03-02 fix: LatLonEditorMode arm logic — inline imports, drop redundant input_utils import
    Importing from orbigator.py would re-execute all module-level init code
    (motors, WiFi, etc.). Inline the three observer imports directly instead.
    Also remove the redundant local `import input_utils` since it is already
    imported at the top of modes.py.
    https://claude.ai/code/session_014H7TD89FRnXuv4wc5PGTdz
    [modes.py]
2026-03-05 Fix blocking TLE fetch loop, web server syntax error, and display offset
    [modes.py, sh1106.py, web_server.py]
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2026-03-10 Fix BOM: UI buttons are included in OLED/Encoder module
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2026-03-22 orbigator v2 pcb ready for fab
    [BarrelJack_Horizontal.step, BatteryHolder_LINX_BAT-HLD-012-SMT.step, C_0805_2012Metric.step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]
2026-03-24 orbigator v2 WIP - not final yet
    [S8201-46R.stp, batt_harwin_S8201-46R.stp.step, bom.csv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]
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2026-03-26 orbigator v2 WIP2 - not final yet
    [BatteryHolder_LINX_BAT-HLD-012-SMT.step, DIP-14_W7.62mm.step, OLED_Display1-F.Fab_.dxf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]
2026-03-28 orbigator v2 production - final
    [Unnamed.FCStd, bom.csv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]
2026-03-28 correct csv formatting for bom
    [orbigator_bom_corrected.csv]
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2026-04-06 Update swingarm production file
    [3_swingarm.stl]
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

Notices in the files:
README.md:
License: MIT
